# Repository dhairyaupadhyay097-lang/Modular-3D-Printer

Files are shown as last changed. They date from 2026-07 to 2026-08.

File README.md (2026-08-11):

# Modular 3D Printer

It's a custom-build, Modular 3DP for rapid prototyping and developing crazy projects. 200 × 200 × 200 mm build volume to print PETG and PLA parts. My main aim for this project is not just building this printer, but learning mechanics, integrating parts built in CAD, and minute configurations needed for next big projects.

## Overview

## Story and Motivation

I have been fascinated by Tony Stark and his approach to engineering since I was young. What interested me most was not simply the technology he used, but the idea of being able to imagine something and then build it in the real world.
As I started working on robotics, electronics, and CubeSat projects, I realized that rapid prototyping was the key. I often imagined custom part but having them seems easy and practical. so, I decided, instead of buying a commercial 3D printer, I'll build one myself. Time was a constrain for me as a student, so I decide to overcome that.
This is not just a printer; it's like skeleton of future projects. It will give shape to every single project I'll make. So, its just the starting of next complex projects and design I have planned. It's also the first one in HCB also so it's kind of special.

## Who Is This Project For?
This project is intended for:
- Students learning mechanics
- Beginners interested in building a 3D printer
- people interested in 3DP
- Robotics and electronics enthusiasts

## Goals
Main aim is to build a medium for me to make other projects' 3D body and prototypes and cutting these printing costs too. Thats for me but for others they may differ

## Features
- 200x200x200mm build volume
- Belt driven X and Y axis
- Lag screw (threaded rods) driven Z axis for better stability
- Marlin firmware
- Heated print bed
- Modular structure
- PLA and PETG printables
- All-metal hotend
- 0.4 mm nozzle
- low cost and beginner friendly prototype

## Specifications

| Specification | Value |
|---|---|
| Build volume | 200 × 200 × 200 mm |
| Nozzle diameter | 0.4 mm |
| Filament | PLA, PETG |
| Typical layer height | 0.1–0.3 mm |
| X-axis | Belt and pulley |
| Y-axis | Belt and pulley |
| Z-axis | Lead screw |
| Hotend | All-metal |
| Cooling | Fan-cooled hotend |
| Firmware | Marlin |
| Heated bed | Yes |
| Target bed temperature | 60 °C |
  
## How It Works
the printer uses three linear motion systems to place print head and build layer together.

### X Axis
This motion is controlled by stepper motor and timing belt with timing belt pulley to move the print head horizontally.


### Y Axis
similar as the X axis one, just the change is that to move whole system and not just the print head, I've use 2 motors to move it back and forth.


### Z Axis
To enhance the stability and due to gravity, I have used lead screws to drive the heatbed up and down.


**For the stability and accuracy i have used smooth rods in all the axis.

### Extruder and Hotend
Filament is fed into the hotend by the extruder motor. The hotend heats the filament until it reaches the required printing temperature, allowing the material to be deposited layer by layer.


### Heated Bed
provides a controlled printing surface and improves first-layer adhesion for materials such as PLA and PETG.

## Electronics
- Arduino mega
- Ramps 1.4 shield
- Nema 17 Stepper motor
- A4988 motor controller
- endstops
- thermistors
- few wires and LEDs ofc
- Cooling fan for hotend
- E3D hotend

## Firmware
The printer uses Marlin firmware running on an Arduino Mega 2560 with a RAMPS 1.4 (shield) control board.
The firmware is configured specifically for this-

- Motion system
- Stepper motor drivers
- Build volume
- Endstops
- Extruder
- Hotend
- Heated bed
- Thermistors

I will upload complete firmware configuration in this repository so that the printer can be reproduced and configured by others.

## CAD and Mechanical Design
All custom CAD designs in this repository were created by me.
The CAD directory contains:

- Complete printer assembly
- Frame components
- Motor mounts
- Extruder components
- X, Y and Z-axis components
- Bed mounting components
- Custom brackets
- Other 3D-printed structural parts

Just get the name of file you need in the CAD section :)

## Bill of Materials
BOM is given above in its section

## Assembly and Printing
For assembly, check the Buildup page and Printing guide.

## Software
- CAD: for mechanical parts and body
- Slicer: Used to convert 3D models into G-code
- Marlin: Firmware used to control the printer's motors, heaters, fans, and sensors.
- Pronterface: Used to send G-code, control the printer, and test/calibrate its systems.

## Testing and Calibration
After assembly, the printer will be tested and calibrated in several stages.

- Mechanical Testing
- Motion Calibration
- Temperature Calibration
- Print Testing

For detail, check the testing page

## Project Photos
No mess here, photos of the build, assembly, and testing process are available in the Gallery
https://github.com/dhairyaupadhyay097-lang/Modular-3D-Printer/tree/main/Images

## Firmware Files
under development

## Future Improvements
- Adding a screen for manual control
- better structure
- better print speed
- fast modelling
- monitoring and filament run out detector
- spaghetti detector too :)

## Problems and Lessons Learned
till now faced tons of problems from CAD and electronic selection and also hope i face them more and more as it will help me to make a better 3DP, i'll update about'em.

## Safety
- Be aware of Hotend and heatbed as they may be hot
- take care of current
- also do not rush to build it
- keep children and untrained users away
- do not leave the printer unattended during testing.
- disconnect power before maintenance or modifications.

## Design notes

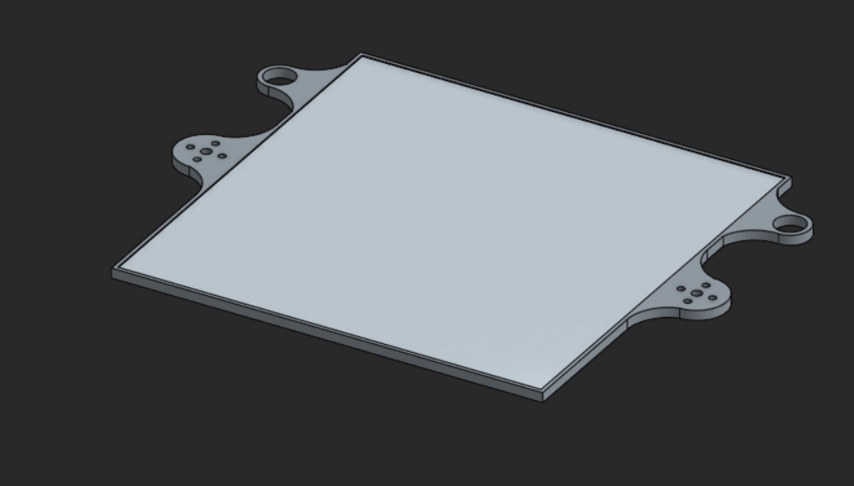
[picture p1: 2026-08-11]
Images/Screenshot_11-8-2026_15353_cad.onshape.com.jpeg

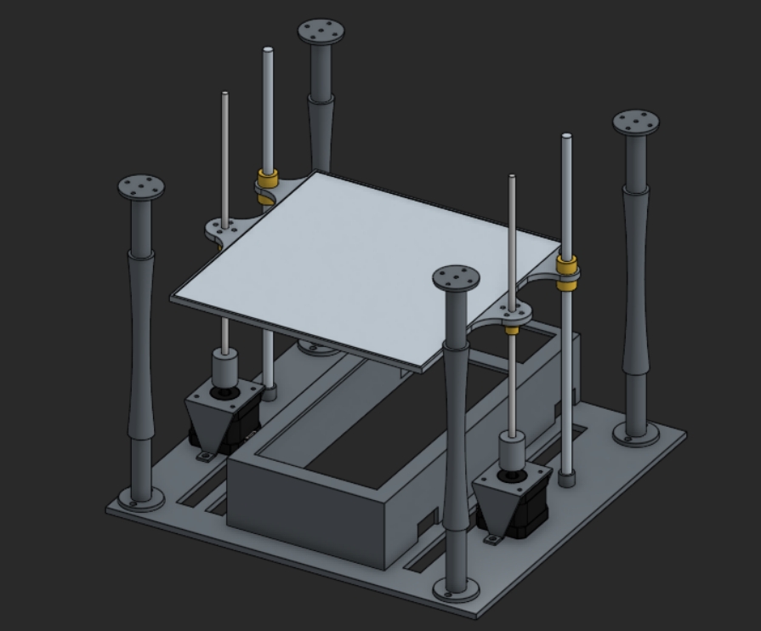
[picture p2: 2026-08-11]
Images/Screenshot_11-8-2026_15724_cad.onshape.com.jpeg

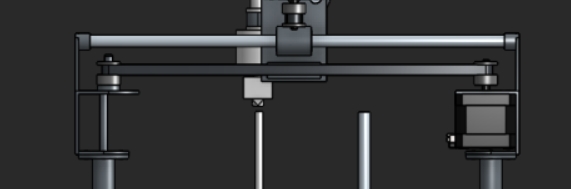
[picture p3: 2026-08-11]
Images/Screenshot_11-8-2026_151136_cad.onshape.com.jpeg

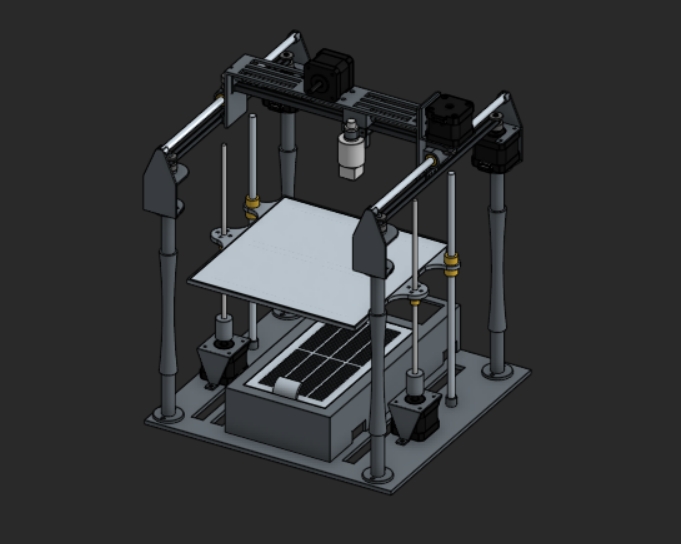
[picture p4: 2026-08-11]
Images/Screenshot_11-8-2026_151145_cad.onshape.com.jpeg

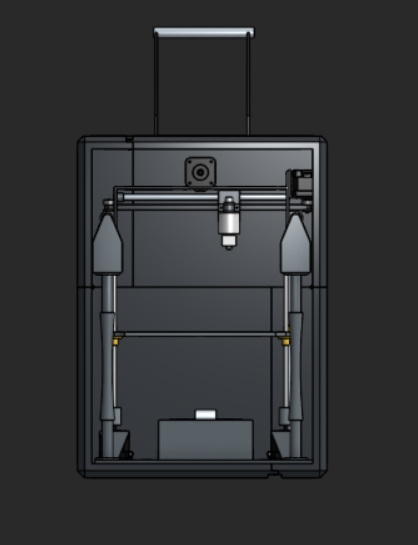
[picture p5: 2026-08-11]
Images/Screenshot_11-8-2026_145912_cad.onshape.com.jpeg

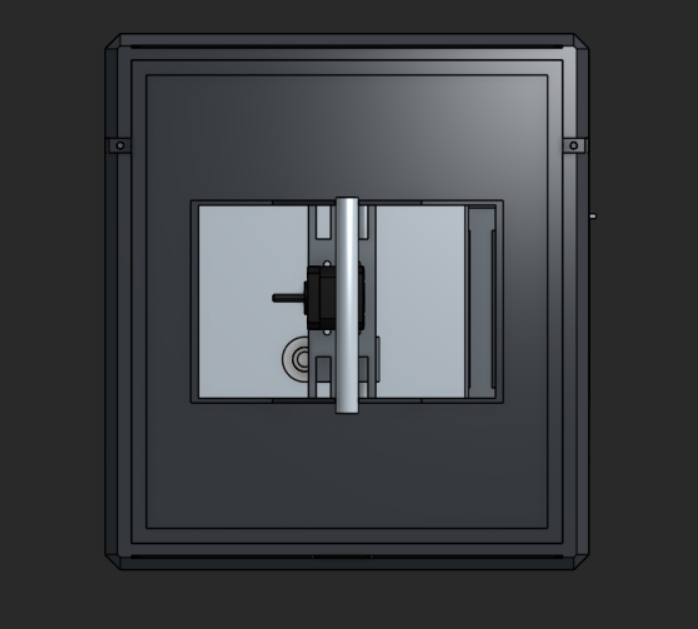
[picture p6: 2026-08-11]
Images/Screenshot_11-8-2026_145947_cad.onshape.com.jpeg

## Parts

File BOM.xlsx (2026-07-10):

Sr. No. | Component | Quantity | Price (₹) | Amount (₹) | Supplier | Link
1 | Arduino Mega | 1 | 2269 | 2269 |  |  | PLA
2 | Nema 17 Stepper Motors | 6 | 799 | 4794 |  | Nema 17 Stepper Motor 42x38 mm, 1.5A, 2 Phase, 4 Wires, 1.8 Degree, 1 Metre Cable for 3D Printers : Amazon.in: Industrial & Scientific (https://www.amazon.in/Stepper-Motor-42x38-Degree-Printers/dp/B0DGQTMKL4) | Rest all
3 | RAMPS 1.4 | 1 | 499 | 499 |  | Robocraze 3D Printer Controller Board RAMPS 1.4 Shield : Amazon.in: Industrial & Scientific (https://www.amazon.in/Robocraze-Printer-Controller-Board-RAMPS/dp/B073B6SHHB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)
4 | A4988 | 1 | 836 | 836 |  | REES52 5Pcs A4988 Stepper Motor Driver Controller Ramps 1.4 Compatible Stepstick Motor Driver Module with Heat Sink for 3D Printer Green (A4988 red) : Amazon.in: Industrial & Scientific (https://www.amazon.in/REES52-Stepper-Controller-Compatible-Stepstick/dp/B07VLLP3HV)
5 | Heatbed | 1 | 699 | 699 |  | Robocraze 3D Printer PCB Heat Bed MK2B 12/24 Dual Power Supply 214 mm 214mm | 3D Printer Project (Pack of 1) : Amazon.in: Industrial & Scientific (https://www.amazon.in/RoboCraze-Printer-Power-Supply-Project/dp/B07MZR6291/)
6 | Smooth Rods (pack of 2) | 3 | 249 | 747 |  | Invento EN31 Steel Smooth Rod for Machines DIY Projects (https://www.amazon.in/Invento-Steel-Smooth-Machines-Projects/dp/B072JJNB2X)
7 | E3D Hotend | 1 | 3343 | 3343 |  | All-Metal V6 J-Head Hotend Extruder Hotend 1.75mm kit for 3D Printers (12V) 0.4mm Nozzle : Amazon.in: Industrial & Scientific (https://www.amazon.in/All-Metal-J-Head-Hotend-Extruder-Printers/dp/B085HLCGHY?s=industrial&xpid=zp4QnwcHGXGzK)
8 | LM8UU Linear Ball Bearings | 1 | 1129 | 1129 |  | INVENTO LM8UU 8 Pieces 8mm Linear Bush Ball Bearing for Reprap Prusa 3D Printer or CNC or Robotic : Amazon.in: Industrial & Scientific (https://www.amazon.in/Invento-LM8UU-Bearing-Printer-Robotic/dp/B01LY8OJ93)
9 | Wires | 1 | 1000 | 1000 |  | many
10 | Power Supply 12V 30A 360W | 1 | 1859 | 1859 |  | INVENTO 1Pcs 12V 30A 360 Watts DC Power supply SMPS AC to DC Converter for CCTV Robotics DIY Projects : Amazon.in: Computers & Accessories (https://www.amazon.in/Invento-INVNT_49-Supply-Robotics-Projects/dp/B01LZBJIKX)
11 | 5mm Threaded Rods (2) | 1 | 409 | 409 |  | INVENTO 2Pcs 300mm (0.3 mtr) SS304 Threaded Rod M5 5mm OD + M5 nut 0.8mm Pitch T Nut Brass round Flange Single Nut for 3D Printer CNC Robotics : Amazon.in: Industrial & Scientific (https://www.amazon.in/INVENTO-Threaded-Flange-Printer-Robotics/dp/B0924Y2XX7)
12 | Ramps 1.4 endstops | 1 | 369 | 369 |  | REES52® Mechanical Endstop Switch Ramps 1.4 Module Limit Switch for RepRap Mendel 3D Printer with 3pin 70cm cable- End Stop Limit Switch- End Stop Button For 3d Printer- Pack of 1 : Amazon.in: Industrial & Scientific (https://www.amazon.in/REES52%C2%AE-Mechanical-Endstop-3d-Printer/dp/B08L3CDWTR)
13 | Soldering ion + wire | 1 | 1584 | 1584 |  | Serplex® 12 in 1 Soldering Iron Kit 80W LCD Adjustable Temperature 180-500℃ Solder Kit Electronics Welding Tools with ON/OFF Switch, Flux, 5 Soldering Tips, Desoldering Pump, Stand, Tweezers-Black : Amazon.in: Industrial & Scientific (https://www.amazon.in/Adjustable-Temperature-Electronics-Desoldering-Tweezers-Black/dp/B0FQ5QHNGY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)
14 | Thermisters (2) | 4 | 74 | 296 |  | Glass-Sealed 100K Ohm NTC 3950 Thermistors - 1% Tolerance - Pack Of 2 : Amazon.in: Industrial & Scientific (https://www.amazon.in/Glass-Sealed-100K-3950-Thermistors-Tolerance/dp/B0BT239B4P)
15 | Timing belt pulley | 6 | 86 | 516 |  | xcluma Aluminum GT2 16Teeth 5mm Bore Timing Belt Pulley Flange Synchronous Wheel for 3D Printers : Amazon.in: Industrial & Scientific (https://www.amazon.in/xcluma-Aluminum-16Teeth-Synchronous-Printers/dp/B098QXY8PG)
16 | GT2 Timing belt | 1 | 284 | 284 |  | 2M GT2 Timing Belt 6mm Wide Open Loop Neoprene Rubber with Fiberglass Core for 3D Printer CNC XY Axis Precision Motion Systems Drive Transmission : Amazon.in: Industrial & Scientific (https://www.amazon.in/Neoprene-Fiberglass-Printer-Precision-Transmission/dp/B0FBLF71KQ)
17 | Zipties | 1 | 209 | 209 |  | Hian 8 Inch Releasable Zip Ties, Reusable Nylon Cable Ties, For Wire Organizers, Home Improvement, Office, Outdoor, DIY Projects, Gardening, Strong, Adjustable, Multi-Use Cable Fasteners (Pack of 100) : Amazon.in: Home Improvement (https://www.amazon.in/Hian-Releasable-Organizers-Improvement-Adjustable/dp/B0D3GZPKTD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)
18 | Glass sheet | 1 | 1912 | 1912 |  | CynKen 1 Piece 1x200x200mm Green FR4 Epoxy Sheet Resin Glass Fiber Insulation Plate About 0.04"x7.9"x7.9" : Amazon.in: Industrial & Scientific (https://www.amazon.in/CynKen-Piece-1x200x200mm-Green-Insulation/dp/B07R3K314K)
19 | Glue gun | 1 | 427 | 427 |  | https://www.amazon.in/gp/product/B07BNQGF57/ref=ox_sc_act_title_2?smid=A2K5VGK3OPN02U&psc=1
20 | 3D Body | 1 | 18017 | 18017 |  | robu.in/cart/
21 | Buffer | 1 | 1000 | 1000
22 | Couplers | 2 | 299 | 598 |  | Robocraze Flexible Couplings 5mm to 8mm with Grub screws NEMA 17 Shaft for RepRap 3D Printer or CNC Machine (Set of 1) | 3D Printer Project : Amazon.in: Industrial & Scientific (https://www.amazon.in/gp/product/B07N1L8WJ2/ref=ox_sc_act_title_2?smid=A1B5UBSQH24ZDS&psc=1)
 |  |  |  | 0
 |  |  |  | 42796

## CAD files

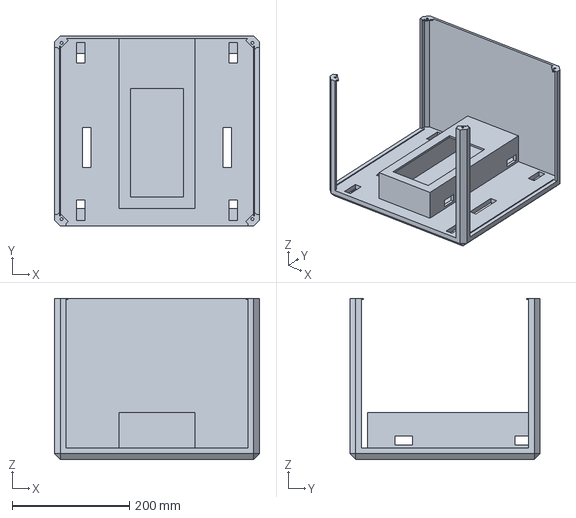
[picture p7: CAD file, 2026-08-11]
CAD/Cover.step
350.0 x 325.0 x 275.0 mm

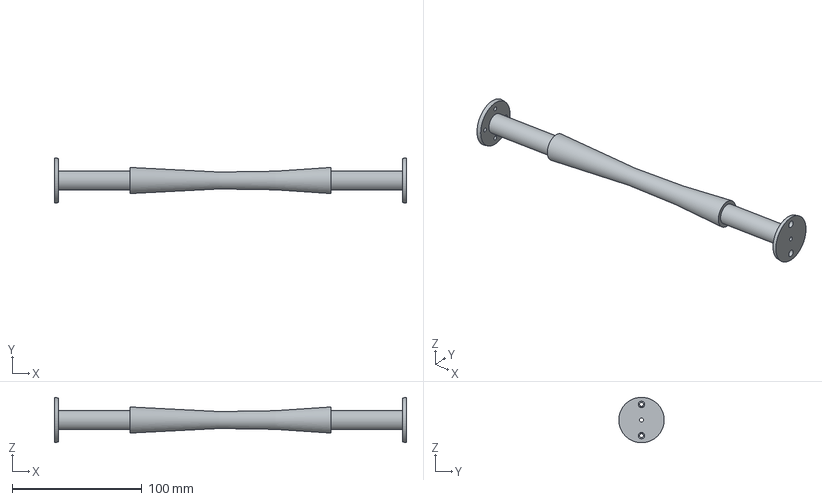
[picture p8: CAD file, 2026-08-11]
CAD/Pillars.step
271.2 x 35.0 x 35.0 mm

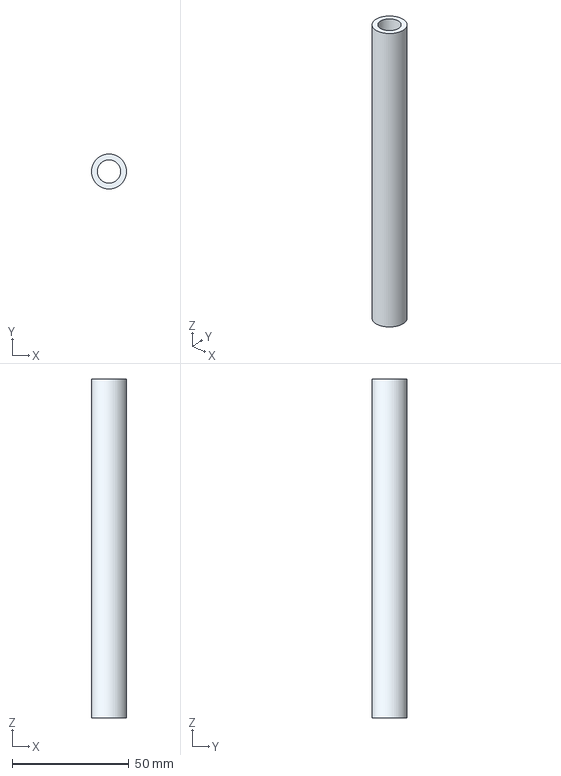
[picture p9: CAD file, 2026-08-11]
CAD/Filament holding rod.step
15.0 x 15.0 x 145.0 mm

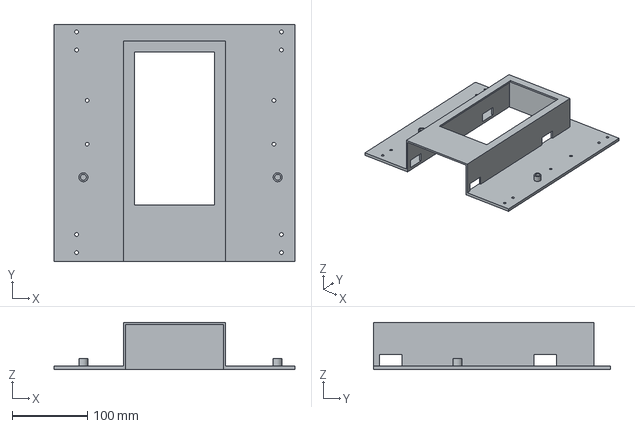
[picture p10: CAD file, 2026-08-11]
CAD/Base.step
320.0 x 315.0 x 63.0 mm

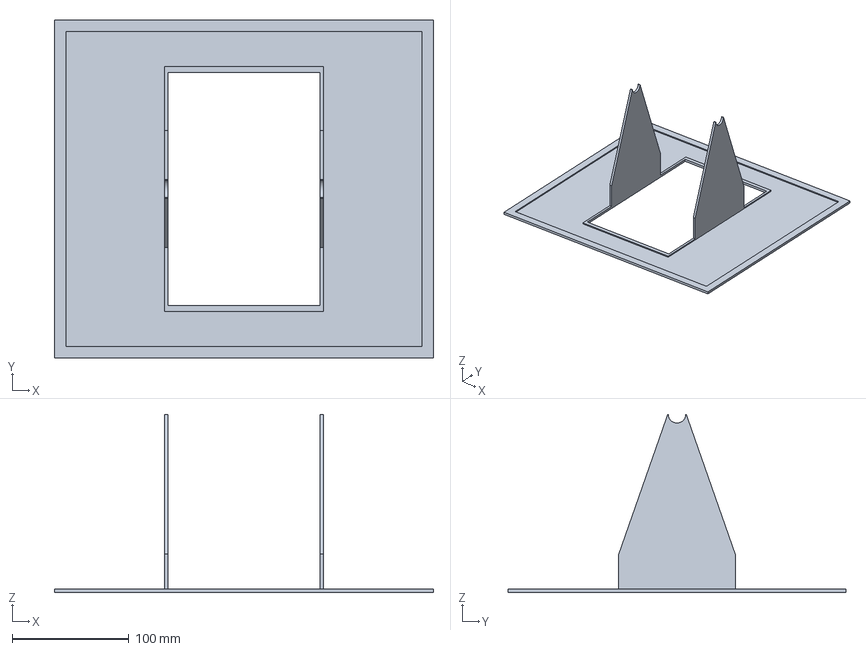
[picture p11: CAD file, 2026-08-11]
CAD/Filament holder.step
325.0 x 290.0 x 153.0 mm

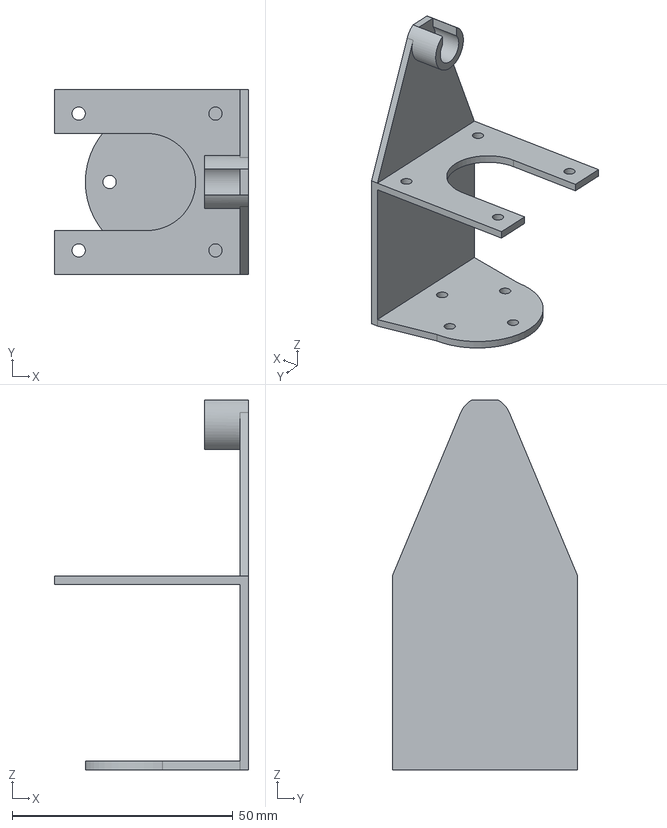
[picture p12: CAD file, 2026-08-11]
CAD/Yaxis nema holder.step
44.0 x 42.0 x 83.8 mm

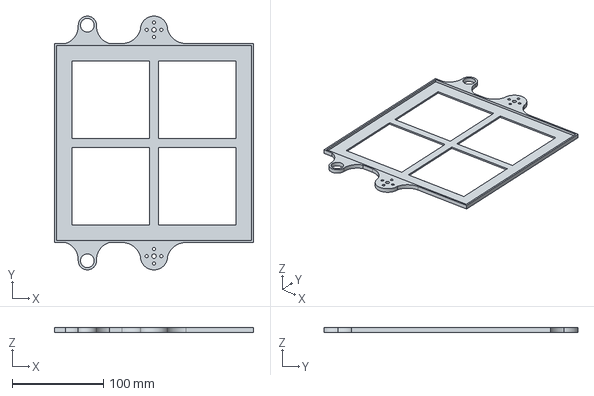
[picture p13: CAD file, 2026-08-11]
CAD/Heatbed holder.step
218.0 x 278.0 x 5.00 mm

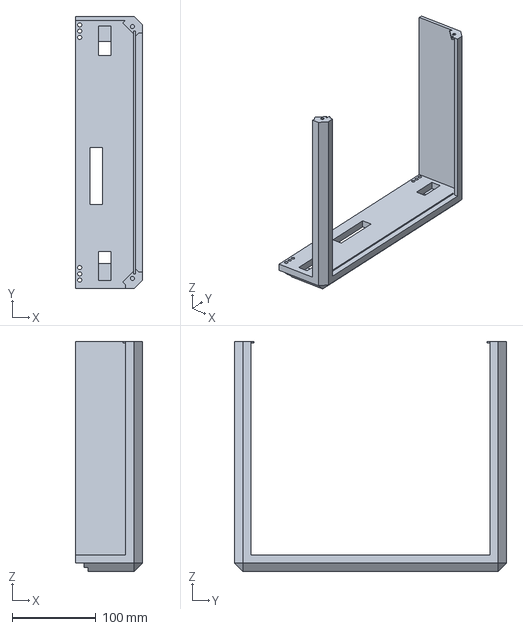
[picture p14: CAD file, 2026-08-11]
CAD/Cover part 2.step
80.0 x 325.0 x 275.0 mm

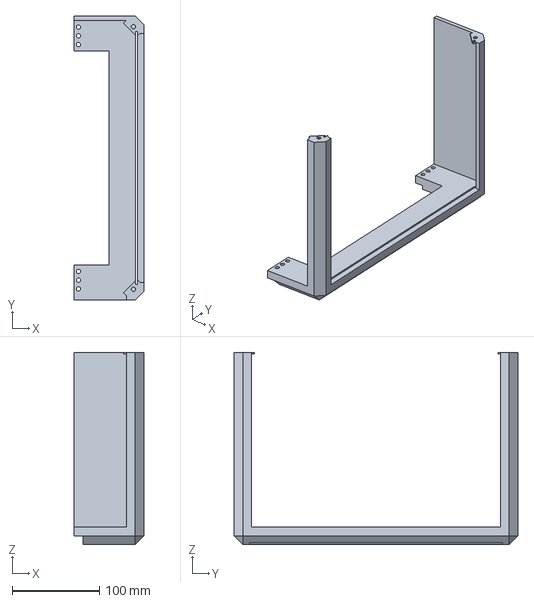
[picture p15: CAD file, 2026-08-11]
CAD/Cover top 2.step
80.0 x 325.0 x 220.0 mm

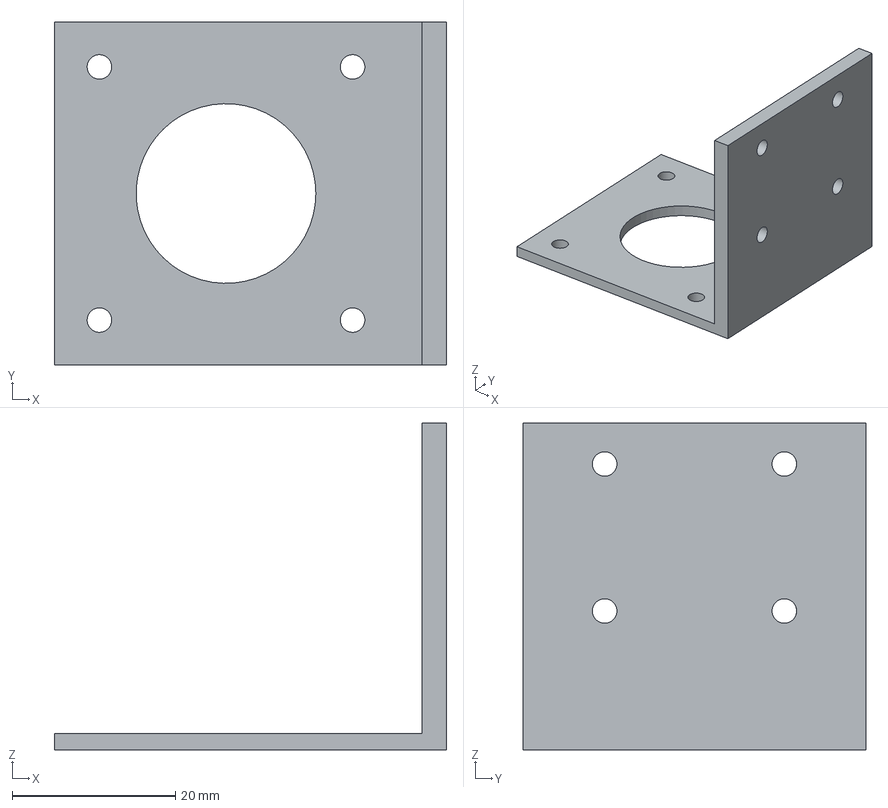
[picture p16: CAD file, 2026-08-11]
CAD/Stepper holder.step
48.0 x 42.0 x 40.0 mm

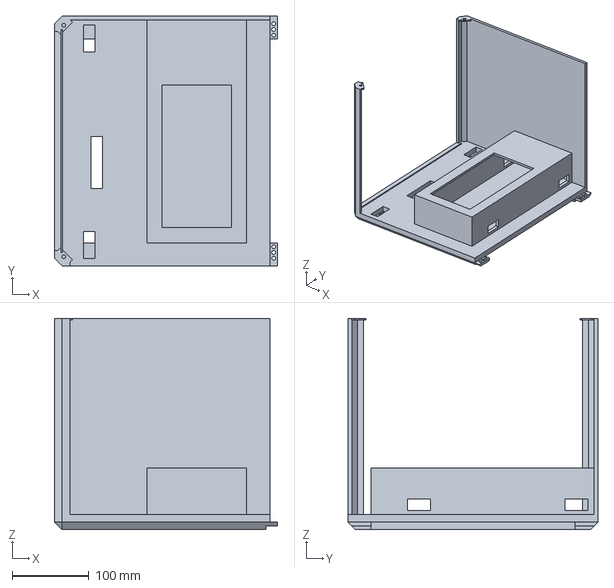
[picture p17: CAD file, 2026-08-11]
CAD/Cover part 1.step
290.0 x 325.0 x 275.0 mm

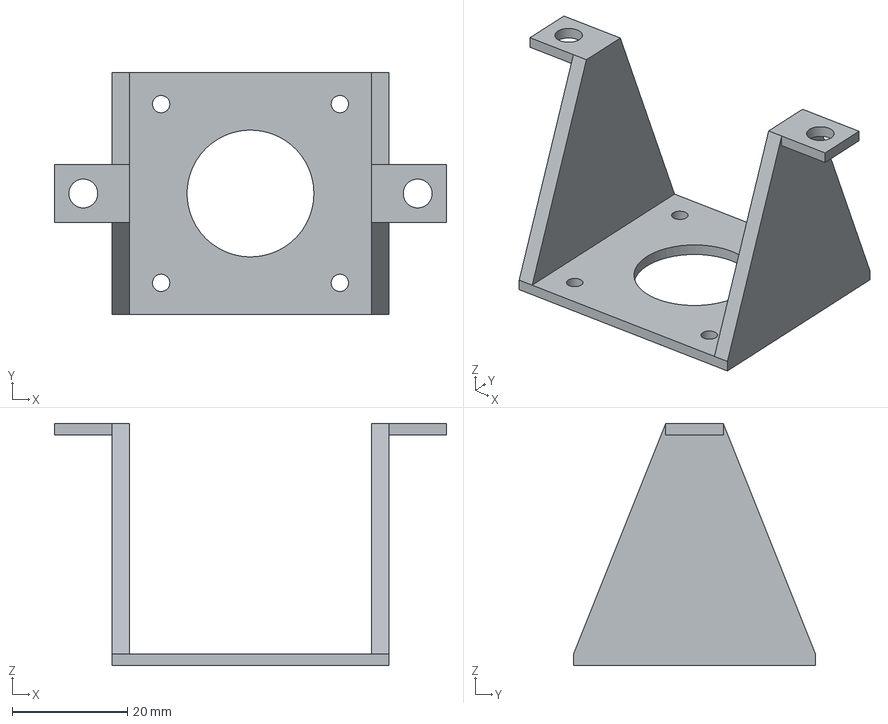
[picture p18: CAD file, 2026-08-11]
CAD/Stepper holder Base.step
68.0 x 42.0 x 42.0 mm

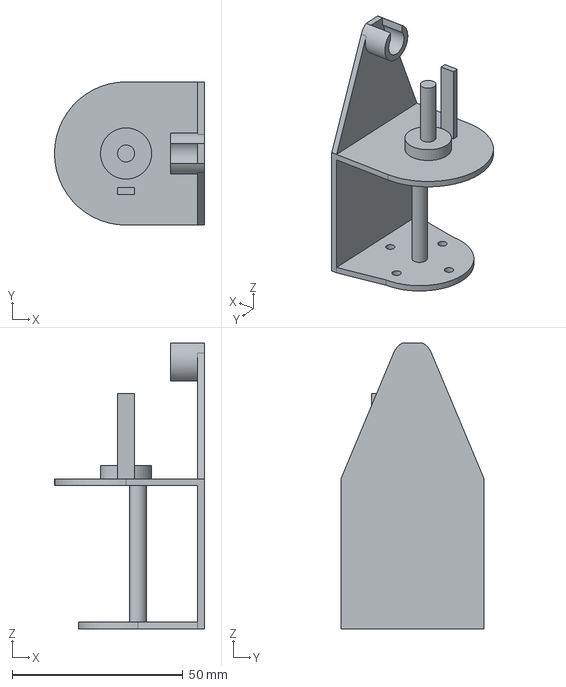
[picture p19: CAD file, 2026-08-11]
CAD/Yaxis nema bore holder.step
44.0 x 42.0 x 83.8 mm

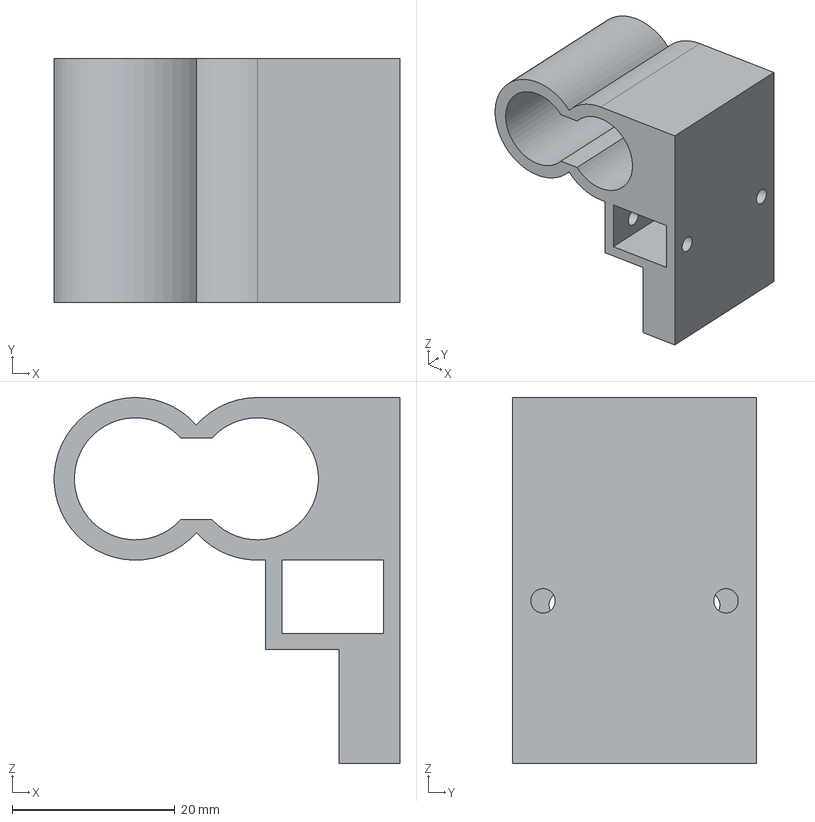
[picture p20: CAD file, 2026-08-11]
CAD/E3D hotend connector.step
42.5 x 30.0 x 45.0 mm

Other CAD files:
CAD/Cover top 1.step
CAD/E3D hotend holder.step
CAD/New top plate.step
CAD/Base cover.step
CAD/Base (1).step
CAD/Cover part 1 (1).step
CAD/Cover part 2 (1).step
CAD/Cover top 1 (1).step
CAD/Cover top 2 (1).step
CAD/New top plate (1).step
CAD/elect. cover.step

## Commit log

2026-07-09 Add BOM file with initial content
2026-07-09 Create Some glimpses of CAD
2026-07-10 Actual BOM
    Made this in excel with all the links of materials used.
    Prices may vary according to the price shown in your device and region.
    [3DP budget list.xlsx]
2026-07-10 Update BOM
2026-07-10 Create Schematic
2026-07-10 Add wiring diagram for Arduino Mega project
    Added a wiring diagram for the project using Arduino Mega and Ramps1.4.
2026-07-12 Rename 3D model to CAD
2026-07-12 Rename 3DP budget list.xlsx to BOM.xlsx
    [BOM.xlsx]
2026-07-13 Create Marlin
2026-08-13 Revise and expand Modular 3D Printer build guide
    Updated the build guide to include detailed assembly instructions, required tools, and safety checks for the Modular 3D Printer.
2026-08-13 Wiring Diagram
    This is the wiring diagram for me, well many more things can be added according to your taste, and i have used basic Arduino mega for my printer
2026-08-15 Rename ImageToStl.com_c083ec3a82524771b1dfd47261ecd8cc.zip to STL files for CAD
